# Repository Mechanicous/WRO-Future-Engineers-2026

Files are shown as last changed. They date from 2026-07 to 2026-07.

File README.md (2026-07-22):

<div align="center">

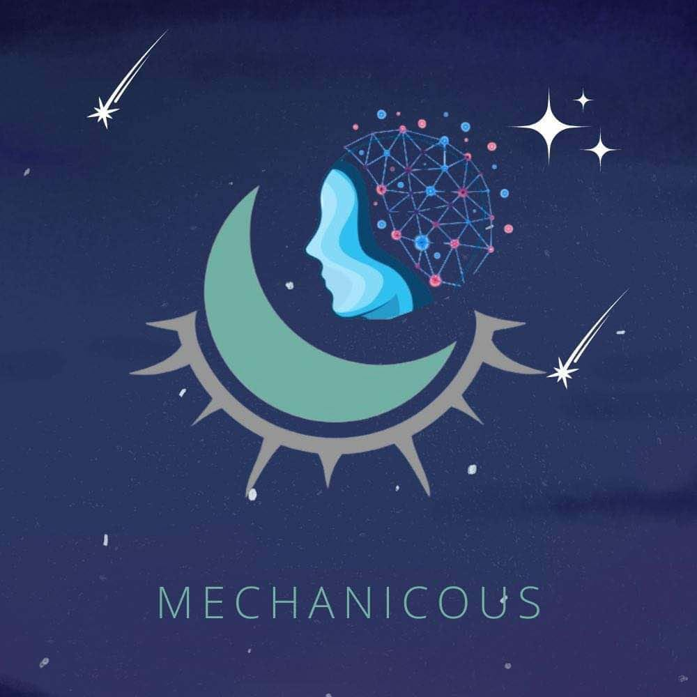
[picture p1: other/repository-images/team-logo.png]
Mechanicous team logo


# Mechanicous - MadBoy

**WRO Future Engineers 2026 engineering documentation**






[Demo Video](#demo-video) | [Rubric Map](#wro-2026-rubric-map) | [Build Guide](#robot-construction-guide) | [Source Code](./src/)

</div>

---

## Table Of Contents

- [Team](#team)
- [Challenge](#challenge)
- [Robot Overview](#robot-overview)
- [WRO 2026 Rubric Map](#wro-2026-rubric-map)
- [Mobility And Mechanical Design](#mobility-and-mechanical-design)
- [Power And Sensor Architecture](#power-and-sensor-architecture)
- [Software Architecture And Obstacle Strategy](#software-architecture-and-obstacle-strategy)
- [Systems Thinking And Engineering Decisions](#systems-thinking-and-engineering-decisions)
- [Robot Construction Guide](#robot-construction-guide)
- [Testing Workflow](#testing-workflow)
- [Demo Video](#demo-video)
- [Cost Report](#cost-report)
- [Repository Structure](#repository-structure)
- [Submission Checklist](#submission-checklist)

---

## Team

<table>
  <tr>
    <td align="center" width="33%">
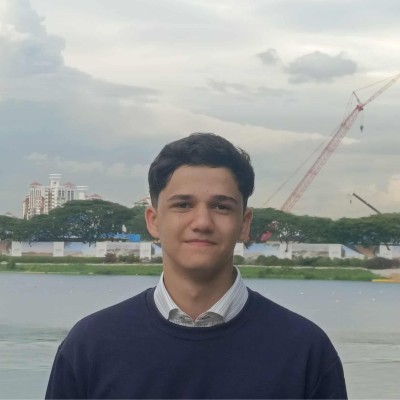
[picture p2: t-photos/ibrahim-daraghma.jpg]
Ibrahim Daraghma team member photo
      <br>
      <strong>Ibrahim Daraghma</strong><br>
      Role: Member<br>
      Focus: Designing And Coding
    </td>
    <td align="center" width="33%">
      Team member photo placeholder<br>
      <strong>Ali Foqha</strong><br>
      Role: Member<br>
      Focus: Coding And Thinking
    </td>
    <td align="center" width="33%">
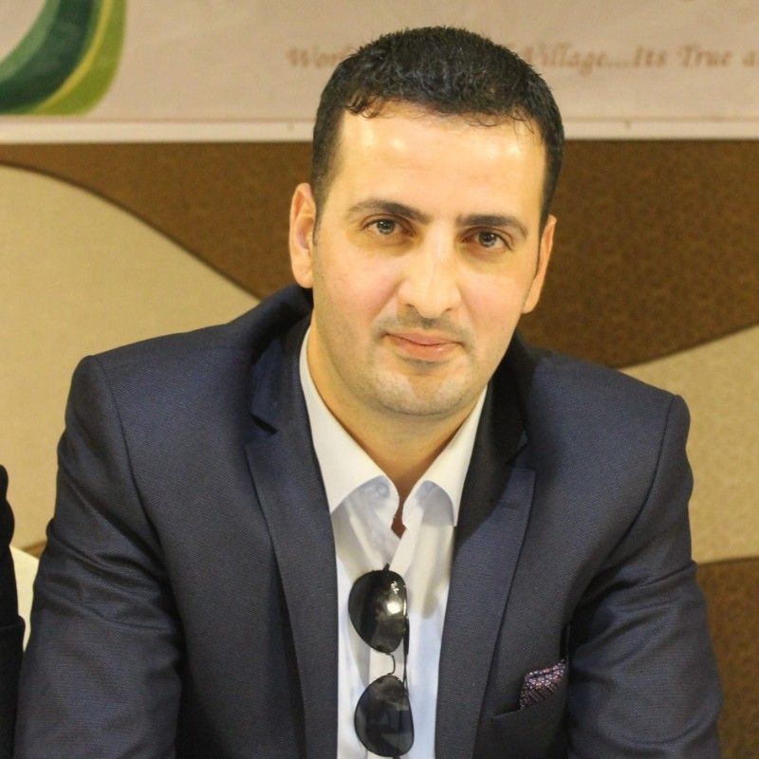
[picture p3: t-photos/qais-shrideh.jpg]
Qais Shrideh coach photo
      <br>
      <strong>Qais Shrideh</strong><br>
      Role: Coach<br>
      Focus: Team guidance
    </td>
  </tr>
</table>

Photos can be found in [`t-photos/`](./t-photos/).

---

## Challenge

WRO Future Engineers 2026 is a self-driving car challenge. The robot must drive autonomously on a field, handle randomized round conditions, complete Open Challenge and Obstacle Challenge runs, and document the full engineering process clearly enough for judges and other teams to understand the design.

The official 2026 documentation rubric is organized around five engineering areas:

- Mobility and mechanical design.
- Power and sensor architecture.
- Software architecture and obstacle strategy.
- Systems thinking and engineering decisions.
- Reproducibility and GitHub quality.

Official rules: [WRO 2026 Future Engineers General Rules](https://wro-association.org/wp-content/uploads/WRO-2026-Future-Engineers-Self-Driving-Cars-General-Rules.pdf)  
Official rubric: [WRO 2026 Future Engineers Documentation Rubric](https://wro-association.org/wp-content/uploads/WRO-2026-Future-Engineers-Documentation-Rubric.pdf)

---

## Robot Overview

<div align="center">

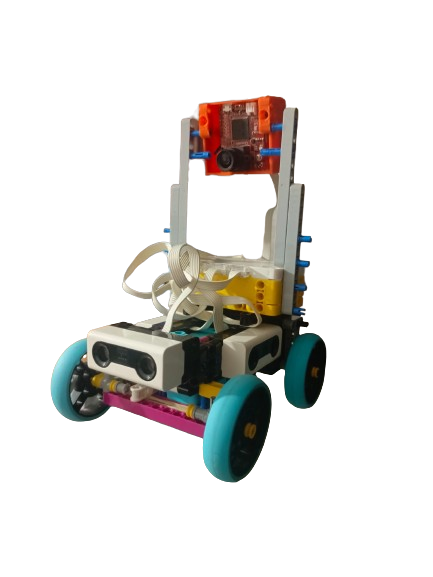
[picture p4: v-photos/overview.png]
MadBoy robot overview photo


</div>

| Item | Current Plan / Evidence |
| --- | --- |
| Robot name | MadBoy |
| Main controller | LEGO SPIKE Prime Hub |
| Programming platform | Pybricks MicroPython |
| Drive system | Rear-wheel drive using a SPIKE Large Angular Motor and rear differential gear system |
| Steering system | Front steering using a SPIKE Medium Angular Motor |
| Sensors | 3x LEGO ultrasonic sensors, SPIKE Prime integrated gyro/IMU, OpenMV H7 camera |
| Stage source code | Open Round: [`src/pybricks/open_round.py`](./src/pybricks/open_round.py); Obstacle Course: [`src/pybricks/obstacle_course.py`](./src/pybricks/obstacle_course.py) |
| Current behavior | Completes 3 laps in the Open Challenge round; Obstacle Challenge detection and strategy are working |
| Next behavior to implement | Improve consistency, tune steering center/wall centering, and add more test evidence |

### Vehicle Photos

Vehicle photos can be found in [`v-photos/`](./v-photos/).

<table>
  <tr>
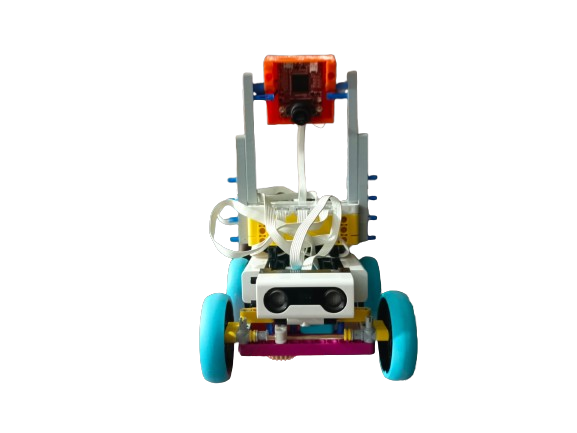
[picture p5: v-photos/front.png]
Front vehicle photo
    <td align="center"><br><strong>Front</strong></td>
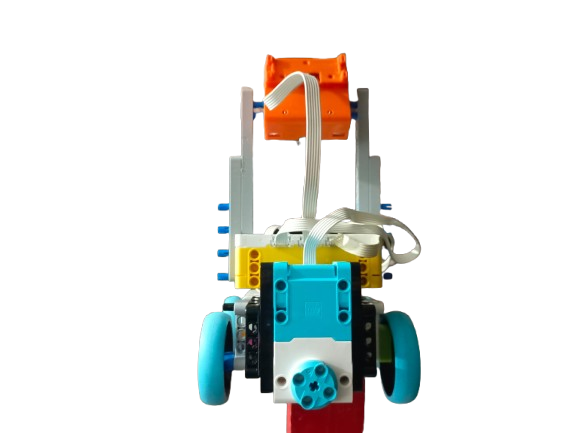
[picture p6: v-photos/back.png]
Back vehicle photo
    <td align="center"><br><strong>Back</strong></td>
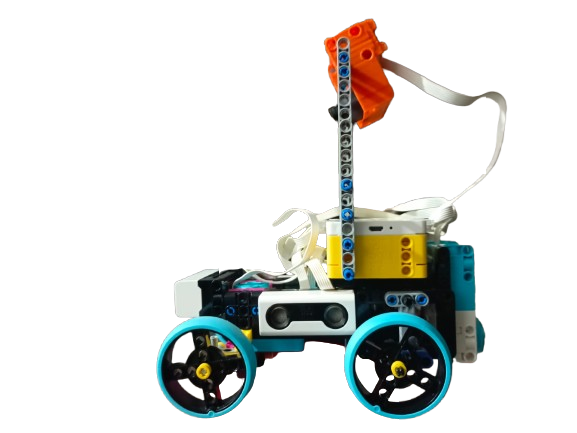
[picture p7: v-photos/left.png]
Left vehicle photo
    <td align="center"><br><strong>Left</strong></td>
  </tr>
  <tr>
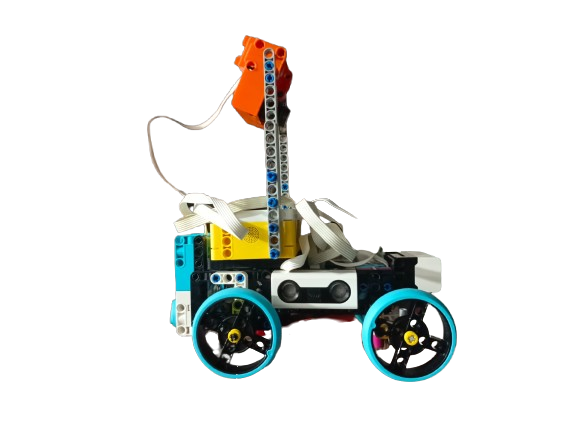
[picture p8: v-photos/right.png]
Right vehicle photo
    <td align="center"><br><strong>Right</strong></td>
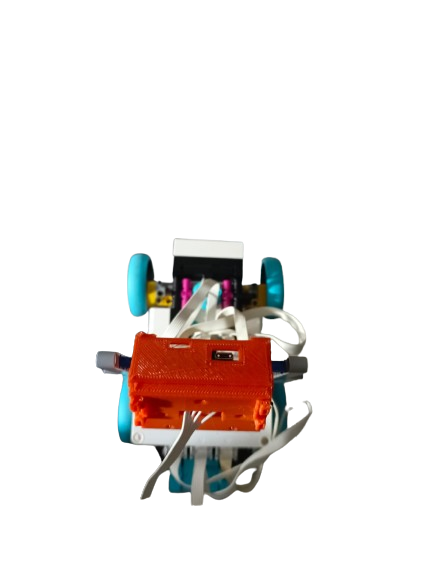
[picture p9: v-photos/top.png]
Top vehicle photo
    <td align="center"><br><strong>Top</strong></td>
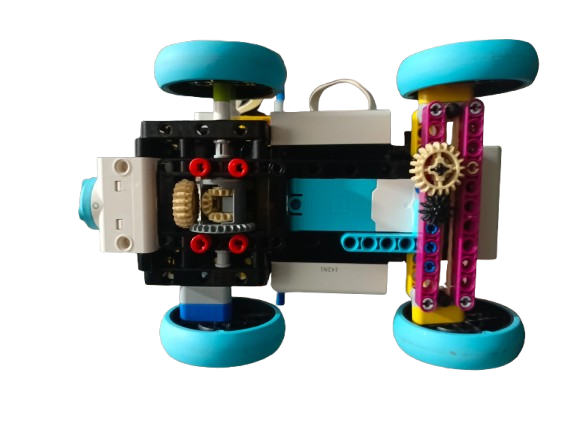
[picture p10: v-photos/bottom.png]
Bottom vehicle photo
    <td align="center"><br><strong>Bottom</strong></td>
  </tr>
</table>

---

## WRO 2026 Rubric Map

Use this table as the judge-facing index for the 2026 documentation rubric.

| 2026 Criterion | What Judges Need To See | Evidence Location | Status |
| --- | --- | --- | --- |
| Mobility and mechanical design | LEGO chassis, steering/drive mechanism, gear reasoning, dimensions, stability, iterations | [`models/Robot_Design.io`](./models/Robot_Design.io), [`v-photos/`](./v-photos/), [Mobility section](#mobility-and-mechanical-design) | Ready for presentation |
| Power and sensor architecture | SPIKE Prime hub, port map, battery/power notes, ultrasonic placement, integrated gyro use, OpenMV H7 UART communication using PUPRemote/LPF2 libraries, calibration, failure handling | [`schemes/`](./schemes/), [`schemes/port-map.md`](./schemes/port-map.md), [`other/calibration.md`](./other/calibration.md), [Power section](#power-and-sensor-architecture) | Ready for presentation |
| Software architecture and obstacle strategy | Pybricks code, gyro heading telemetry, flowchart/state machine, wall-following, OpenMV obstacle strategy, edge cases, tests | [`src/`](./src/), [`docs/software-architecture.md`](./docs/software-architecture.md), [Software section](#software-architecture-and-obstacle-strategy) | Documented; final code upload pending |
| Systems thinking and engineering decisions | Why LEGO SPIKE Prime was chosen, tradeoffs, risks, version history, testing response | [`docs/decisions.md`](./docs/decisions.md), [Decisions section](#systems-thinking-and-engineering-decisions) | Ready for presentation |
| Reproducibility and GitHub quality | README, source code, build steps, photos, diagrams, tests, meaningful commits | [`docs/build-instructions.md`](./docs/build-instructions.md), [`docs/tests.md`](./docs/tests.md), [Repository structure](#repository-structure) | Ready; final code upload pending |

---

## Mobility And Mechanical Design

### Mechanical Summary

| Subsystem | Design | Reasoning | Evidence |
| --- | --- | --- | --- |
| Chassis | LEGO SPIKE Prime / Technic construction, about 20 cm long x 13.5 cm wide x 22 cm high | Fast rebuilds, repeatable geometry, simpler maintenance, and within the WRO FE 30 cm x 20 cm x 30 cm size limit | [`v-photos/`](./v-photos/), [`models/Robot_Design.io`](./models/Robot_Design.io) |
| Drive motor | SPIKE Large Angular Motor driving a 20-tooth double bevel gear into a 28-tooth differential gear | Rear-wheel traction with smoother turning between left/right rear wheels | Approx. 20:28 reduction, wheel diameter about 5.5 cm; add speed tests |
| Steering | SPIKE Medium Angular Motor drives a 12-tooth gear into a 20-tooth gear, moving an arm linkage that steers the front wheels | Dedicated steering actuator keeps drive and steering control separate; 12:20 reduction improves steering torque | Steering range is about 45 degrees left and 45 degrees right |
| Sensors | Left/middle/right ultrasonic sensors, integrated gyro, OpenMV H7 | Distance, heading feedback, and vision/color detection | Sensor and camera heights documented below |
| Mounting | LEGO beams, frames, and pins | Easy iteration and legal reproducibility | Add build photos/model files |

### Powertrain

The robot uses rear-wheel drive. A SPIKE Large Angular Motor drives a beige 20-tooth double bevel gear, which drives the 28-tooth gear on the LEGO differential. This creates an approximate 20:28 reduction, so the differential turns about 0.71 times for each motor gear rotation while increasing torque by about 1.4x before friction losses. The differential contains three 12-tooth bevel gears so the left and right rear wheels can rotate at different speeds while turning.

### Dimensions

| Measurement | Approximate Value | Notes |
| --- | ---: | --- |
| Length | 20 cm | Within WRO FE 30 cm maximum length |
| Width | 13.5 cm | Within WRO FE 20 cm maximum width |
| Height | 22 cm | Within WRO FE 30 cm maximum height |
| Wheelbase | 10.3 cm | Front axle center to rear axle center |
| Front track width | 11.2 cm | Left front wheel center to right front wheel center |
| Rear track width | 11.2 cm | About the same as front track width |
| Wheel diameter | 5.5 cm | LEGO wheel/tire diameter |

Current size check: MadBoy fits inside the WRO Future Engineers 2026 maximum robot size of 30 cm length x 20 cm width x 30 cm height.

| Test | Result | What Changed |
| --- | --- | --- |
| Straight-line run | Completes 3 Open Challenge laps | Current drivetrain retained |
| Corner entry | Handles Open Challenge corners during completed 3-lap runs | Keep tuning for consistency |
| Three-minute endurance | Battery shows no noticeable slowdown during current runs | Exact runtime not measured |

### Steering

The robot uses a SPIKE Medium Angular Motor for steering. The motor drives a 12-tooth gear, which drives a 20-tooth gear connected to an arm linkage. Moving this arm moves the steering system and turns the front wheels. The maximum steering range is about 45 degrees left and 45 degrees right, which matches the `STEERING_LEFT_LIMIT_DEG = -45` and `STEERING_RIGHT_LIMIT_DEG = 45` limits in [`src/pybricks/open_round.py`](./src/pybricks/open_round.py).

### Chassis

The robot design is available as a Studio 2.0 file at [`models/Robot_Design.io`](./models/Robot_Design.io). It includes the step-by-step building instructions for MadBoy.

Use the model and build photos in [`models/`](./models/) to explain:

- Why the LEGO frame shape was chosen.
- How the hub, motors, and ultrasonic sensors are mounted.
- How weight is distributed.
- What changed between versions.

---

## Power And Sensor Architecture

### SPIKE Prime Port Map

Keep the active port map in [`schemes/port-map.md`](./schemes/port-map.md).

| Device | Current Port | Purpose | Notes |
| --- | --- | --- | --- |
| Drive motor | A | SPIKE Large Angular Motor for rear-wheel drive | Confirmed |
| Steering motor | E | SPIKE Medium Angular Motor for front steering | Confirmed |
| Left ultrasonic sensor | B | Measure left wall distance | Confirmed |
| Middle/front ultrasonic sensor | D | Measure front path and obstacle distance | Confirmed |
| Right ultrasonic sensor | F | Measure right wall distance | Confirmed |
| Integrated gyro/IMU | SPIKE Prime Hub | Heading and turn feedback | Built into hub |
| OpenMV H7 camera | C | Vision and obstacle color detection | Confirmed UART protocol; PUPRemote/LPF2 libraries used in code |

### Power Distribution

The LEGO SPIKE Prime rechargeable battery powers the hub and connected Powered Up motors/sensors through the hub ports. Before each run, the team charges the hub battery to full, checks that every cable is connected, confirms that the LEGO structure is steady and sturdy, and verifies that all motors, sensors, and camera parts are in place.

Current battery evidence is qualitative: the SPIKE Prime Hub battery lasts a long time during team testing, and no noticeable slowdown has been reported during current Open Challenge runs. Exact runtime has not been tracked yet.

| Connection | Details |
| --- | --- |
| Power source | SPIKE Prime rechargeable battery inside the hub |
| Motor/sensor power | Hub ports power the two motors and three ultrasonic sensors |
| OpenMV link | UART on SPIKE Prime port C, with PUPRemote/LPF2 Python libraries packaging messages |
| Pre-run check | Full battery, firm cables, sturdy LEGO frame, all sensors/motors/camera in place |

### Sensor Placement

| Sensor | Position | Purpose | Calibration |
| --- | --- | --- | --- |
| Left ultrasonic | Left side, about 5 cm from the floor, facing outward to the left | Wall distance and lane centering | Test readings at known distances |
| Middle/front ultrasonic | Middle/front, about 6 cm from the floor, facing forward | Front safety stop and obstacle approach distance | Test close-range stop threshold |
| Right ultrasonic | Right side, about 5 cm from the floor, facing outward to the right | Wall distance and lane centering | Test readings at known distances |
| Integrated gyro/IMU | Inside SPIKE Prime Hub, hub lying flat with USB port facing left | Heading tracking and turn feedback | Reset heading at start line and test drift |
| OpenMV H7 camera | Lens about 17.5 cm from the floor, tilted about 5 degrees | Red/green obstacle detection and vision strategy | Calibrate thresholds after mounting |

The OpenMV H7 communicates with the SPIKE Prime Hub on port C using the UART communication protocol. The code uses the PUPRemote/LPF2 Python libraries to package and exchange the data.

### Failure Handling

| Failure Mode | Detection | Response |
| --- | --- | --- |
| Front sensor reports too close | Front distance below threshold | Stop drive motor |
| Front sensor unavailable | Reading rejected by software | Stop until reading returns |
| Left/right sensor noisy or out of range | Clamp steering correction | Keep steering limited |
| Gyro heading drift | Heading check becomes inaccurate | Reset at start and record drift tests |
| OpenMV unavailable or uncalibrated | Vision-based obstacle classification is unavailable | Fall back to safe behavior until integration is tested |
| Low hub battery | Battery not fully charged before a run | Charge the SPIKE Prime Hub battery to full before testing or official runs |

---

## Software Architecture And Obstacle Strategy

### Stage Code

The robot software is organized by stage:

- [`src/pybricks/open_round.py`](./src/pybricks/open_round.py) is used for the Open Challenge / Open Round stage.
- [`src/pybricks/obstacle_course.py`](./src/pybricks/obstacle_course.py) is reserved for the Obstacle Challenge stage and currently contains `#soon` until the team publishes that code.

The Open Round program currently:

- Runs on a LEGO SPIKE Prime Hub using Pybricks MicroPython.
- Reads three ultrasonic sensors: left, middle/front, and right.
- Resets and reads the SPIKE Prime integrated gyro heading.
- Uses the middle/front ultrasonic sensor as a safety stop.
- Completes 3 laps in the Open Challenge round.
- Uses left/right distance difference for wall-balancing steering.
- Uses `src/openmv/` for OpenMV H7 vision code and UART communication notes.
- Keeps all port assignments and control constants near the top of the file for easy tuning.

### Current Flow

```mermaid
flowchart TD
    A["Power on SPIKE Prime"] --> B["Initialize hub, motors, ultrasonic sensors, and gyro"]
    B --> C["Wait for center button"]
    C --> D["Center steering and reset gyro heading"]
    D --> E["Read distances and heading"]
    E --> F{"Front distance safe?"}
    F -- "No" --> G["Stop drive motor"]
    F -- "Yes" --> H["Compare left and right distances"]
    H --> I["Calculate steering correction"]
    I --> J["Drive forward"]
    G --> E
    J --> E
```

### Final State Machine Template

| State | Purpose | Entry Condition | Exit Condition | Notes |
| --- | --- | --- | --- | --- |
| Init | Verify ports, sensors, motors, and battery | Program start | Hardware ready | Implemented in starter code |
| WaitForStart | Keep robot still before official run | Hub center button or start condition | Start pressed | Implemented in starter code |
| OpenChallengeDrive | Complete 3 laps without colored obstacles | Open Challenge run starts | 3 laps complete or timeout | Working |
| WallCentering | Maintain position using side ultrasonic sensors | Driving straight/curving | Corner or obstacle detected | Starter code exists |
| ObstacleDetect | Detect obstacle approach with front sensor and OpenMV H7 vision | Obstacle Challenge | Obstacle classified | Working |
| AvoidRed | Pass red obstacle according to WRO rules | Red obstacle detected | Safe path restored | Working |
| AvoidGreen | Pass green obstacle according to WRO rules | Green obstacle detected | Safe path restored | Working |
| Parking | Not used by team strategy | Parking/start-from-parking not selected | N/A | Not planned |
| FailSafeStop | Stop safely | Unsafe or invalid readings | Manual reset or safe reading | Starter code exists |

### Algorithms To Explain

- Wall centering from left/right ultrasonic sensors.
- Heading feedback from the SPIKE Prime integrated gyro.
- Front obstacle distance threshold.
- Corner detection.
- Lap counting.
- Obstacle color detection strategy using OpenMV H7.
- Recovery from bad ultrasonic readings.
- Steering calibration and sign testing.

---

## Systems Thinking And Engineering Decisions

Judges look for the reasoning behind the design, not only the final robot.

| Decision | Options Compared | Chosen Option | Why | Test Evidence |
| --- | --- | --- | --- | --- |
| Controller platform | Arduino custom electronics vs LEGO SPIKE Prime | LEGO SPIKE Prime | Faster iteration, integrated battery, robust ports, Pybricks support | Current robot completes 3 Open Challenge laps |
| Programming language | Arduino C++ vs Pybricks MicroPython | Pybricks MicroPython | Cleaner high-level motor/sensor APIs and easier tuning | Stage code in `src/pybricks/open_round.py` and `src/pybricks/obstacle_course.py` |
| Distance sensing | VL53L1X ToF vs LEGO ultrasonic | Three LEGO ultrasonic sensors | Matches new LEGO build and simple wall-distance measurements | 20 cm calibration recorded |
| Heading feedback | External IMU vs SPIKE Prime integrated gyro | SPIKE Prime integrated gyro | Built into the hub and available through Pybricks | Orientation documented; MadBoy drift measurement still needed |
| Vision sensor | No camera vs OpenMV H7 | OpenMV H7 | Supports red/green obstacle detection with onboard vision processing and UART communication to the SPIKE Hub using PUPRemote/LPF2 libraries | Obstacle detection and strategy working |
| Navigation strategy | Gyro heading hold vs ultrasonic wall centering vs fused approach | Ultrasonic wall centering plus integrated gyro feedback | Uses current sensors while keeping heading data available | Current wall-centering behavior documented |

### Iteration Log

| Version | Change | Problem Solved | Evidence |
| --- | --- | --- | --- |
| v0.1 | Arduino prototype with BMI160 and VL53L1X sensors | First heading-hold experiment | Git history |
| v0.2 | Switched to LEGO SPIKE Prime, Pybricks, and 3 ultrasonic sensors | Simpler integrated robot platform | Current README and source |
| v0.3 | Added integrated gyro, OpenMV H7, confirmed ports, dimensions, tests, and BOM | Prepared repository for presentation | Current README, docs, photos, and test logs |

### Risks

| Risk | Impact | Mitigation | Test |
| --- | --- | --- | --- |
| Ultrasonic reflections | Wrong distance near angled walls or obstacles | Use repeated tests, clamp steering, tune thresholds | 20 cm calibration recorded; more distances recommended |
| Gyro heading drift | Turns or lap logic may become inaccurate | Reset at start and test drift over time | Internet reference documented; MadBoy measurement still needed |
| OpenMV lighting sensitivity | Red/green detection may fail under different lighting | Calibrate thresholds on the real field | Detection/strategy working; formal accuracy count still needed |
| Steering sign reversed | Robot steers into wall | Test at low speed and flip `STEERING_SIGN` if needed | Current sign passes: closer to left wall steers right/away |
| LEGO structure flex | Sensor angle or steering changes during run | Reinforce mounts and inspect after runs | Pre-run structure check documented |
| Hub battery low | Motor speed changes during run | Charge to full before each run and check cable/structure stability | No noticeable slowdown reported; exact runtime not tracked |

Detailed decision records belong in [`docs/decisions.md`](./docs/decisions.md).

---

## Robot Construction Guide

The complete mechanical construction guide is stored in [`models/Robot_Design.io`](./models/Robot_Design.io). Open it with Studio 2.0 to view the full MadBoy model and follow the included step-by-step building instructions. No separate written LEGO assembly guide is needed because the Studio file is the official build reference.

Additional setup notes are in [`docs/build-instructions.md`](./docs/build-instructions.md), including dimensions, port wiring, sensor placement, software upload, and the pre-run checklist.

### Upload Pybricks Code

1. Install Pybricks firmware on the SPIKE Prime Hub if it is not already installed.
2. Open [Pybricks Code](https://code.pybricks.com/) in a browser.
3. Connect the SPIKE Prime Hub.
4. Open the program for the current stage: [`src/pybricks/open_round.py`](./src/pybricks/open_round.py) for Open Round, or [`src/pybricks/obstacle_course.py`](./src/pybricks/obstacle_course.py) when the Obstacle Course code is published.
5. Confirm the port constants match the real robot.
6. Upload/run the program.
7. Start at low speed and verify steering direction before full-speed tests.

---

## Testing Workflow

Testing evidence belongs in [`docs/tests.md`](./docs/tests.md).

| Test | Metric | Target | Current Result |
| --- | --- | --- | --- |
| Ultrasonic accuracy | Error at known distances | +/- 1 cm reference target | 20 cm test: left +0.5 cm, front +1.2 cm, right +0.1 cm |
| Gyro heading drift | Degrees drift over time | Measure MadBoy; internet bad-case reference up to about 1 deg/s | Not measured yet on MadBoy |
| Front safety stop | Stop distance from obstacle | Object at 10 cm | Robot stopped at about 10 cm, +/- 1 cm |
| Steering center | Straight run drift | Straight run after centering | Drifts left or right depending on the last steering adjustment |
| Steering sign | Correct response to left/right offset | Closer to left wall should steer right/away | Passes with `STEERING_SIGN = 1` |
| Wall centering | Average side-distance error | Stay between walls during Open Challenge | Sometimes centered; sometimes closer to one wall, so side gain and steering center need tuning |
| Rear differential smoothness | Binding, clicking, or slipping | Smooth rear-wheel drive | Drives smoothly with LEGO gears; no binding/slipping observed |
| Open Challenge | Laps and time | 3 laps | Working: completes 3 laps |
| OpenMV color detection | Red/green classification accuracy | Working obstacle detection | Detection working; add formal accuracy test later |
| Obstacle Challenge | Obstacle handling and score | Working detection and strategy | Strategy ready and working |
| Parking | Final position and alignment | Not used | Team will not park or start from parking area |

---

## Demo Video

Add public video links in [`video/video.md`](./video/video.md).

| Video | Link | Robot Version | Date |
| --- | --- | --- | --- |
| Open Challenge run | [YouTube](https://youtu.be/ipjWBAg2dVM) | MadBoy | July 21, 2026 |
| Obstacle Challenge run | Not published yet | MadBoy | Evidence pending |

---

## Cost Report

Maintain the full bill of materials in [`other/bill-of-materials.md`](./other/bill-of-materials.md). The current robot used parts that were already available to the team, so the actual team spending for the listed robot electronics is 0 USD. The replacement-cost estimate below is for another team buying the main electronics separately.

| Category | Estimated Cost | Notes |
| --- | ---: | --- |
| Actual team spending | 0 USD | Parts were already available |
| Main electronics replacement estimate | about 669 USD | Hub, Large Angular Motor, Medium Angular Motor, three ultrasonic sensors, OpenMV H7 |
| LEGO structural parts | Variable / already available | Beams, frames, wheels, gears, differential |
| Power | Included / already available | SPIKE Prime rechargeable battery and charger/cable |
| Total replacement estimate | about 669 USD plus variable LEGO structure cost | See detailed BOM |

---

## Repository Structure

| Folder | Purpose |
| --- | --- |
| [`src/`](./src/) | Pybricks MicroPython robot code and OpenMV H7 vision notes |
| [`schemes/`](./schemes/) | SPIKE Prime port map, gyro/camera notes, sensor placement, and power/connection diagrams |
| [`models/`](./models/) | Studio 2.0 LEGO model, build instructions, build photos, and reproducible assembly notes |
| [`v-photos/`](./v-photos/) | Vehicle photos from all required angles |
| [`t-photos/`](./t-photos/) | Team photos |
| [`video/`](./video/) | Demo video links |
| [`docs/`](./docs/) | Engineering journal, build guide, tests, decisions |
| [`other/`](./other/) | BOM, calibration notes, datasets, hardware specs, supporting assets |

Sensor reference values from LEGO and Pybricks are summarized in [`docs/sensor-reference.md`](./docs/sensor-reference.md).

---

## Submission Checklist

- [ ] Team details and team photos are complete. Missing Ali Foqha photo.
- [x] Vehicle photos show front, back, left, right, top, bottom, wiring/ports, and sensors.
- [x] README explains the LEGO SPIKE Prime robot clearly and links to all evidence.
- [ ] Engineering journal tells the design story and includes reasoning. Needs more dated narrative entries from the team.
- [x] Mechanical design includes LEGO model/build files, photos, and dimensions.
- [x] SPIKE Prime port map and sensor placement measurements are included.
- [x] Ultrasonic sensor calibration is documented.
- [ ] Integrated gyro heading reset/drift tests are documented with MadBoy measurements.
- [x] OpenMV H7 mounting, calibration plan, and communication method are documented.
- [x] Software architecture includes flowchart/state machine and obstacle strategy.
- [x] Tests include results, metrics, and changes made after testing.
- [x] Decisions include alternatives, tradeoffs, and risks.
- [x] Build instructions let another team reproduce the robot.
- [ ] Demo video links are public. Open Challenge video is public; Obstacle Challenge video is still pending.
- [x] Git history has meaningful commits.

---

## License

This project is released under the [MIT License](./LICENSE).

Third-party PUPRemote/LPF2 communication libraries are listed in
[`THIRD_PARTY_NOTICES.md`](./THIRD_PARTY_NOTICES.md).

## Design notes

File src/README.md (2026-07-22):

# Source Code

This folder contains the stage-specific robot software.

## Stage Programs

- `pybricks/open_round.py` is used for the Open Challenge / Open Round stage.
- `pybricks/obstacle_course.py` is reserved for the Obstacle Challenge stage and will be filled when the team is ready to publish that code.

The project now uses:

- LEGO SPIKE Prime Hub.
- Pybricks MicroPython.
- LEGO SPIKE Prime integrated gyro/IMU for heading feedback.
- Three LEGO ultrasonic sensors:
  - Left.
  - Middle/front.
  - Right.
- OpenMV H7 camera module for vision/color detection.

The old Arduino/BMI160/VL53L1X prototype is no longer active. It remains available in Git history for reference, but the repository documentation now follows the LEGO SPIKE Prime design.

## Current Behavior

- Initializes the SPIKE Prime Hub, rear-drive Large Angular Motor, steering Medium Angular Motor, and three ultrasonic sensors.
- Resets and reports the SPIKE Prime integrated gyro heading.
- Waits for the hub center button before driving.
- Stops when the middle/front ultrasonic sensor reports an unsafe distance.
- Completes 3 laps in the Open Challenge round.
- Uses left/right ultrasonic distance difference for wall-centering steering.
- Prints simple telemetry for tuning.

## Files

| File | Purpose |
| --- | --- |
| `pybricks/open_round.py` | Open Challenge / Open Round program using gyro heading and ultrasonic distance correction |
| `pybricks/obstacle_course.py` | Obstacle Challenge program location; currently reserved until the team publishes this stage code |
| `pybricks/README.md` | Pybricks setup, port constants, and tuning notes |
| `lib/pybricks/pupremote_hub.py` | Hub-side PUPRemote library for reading OpenMV data |
| `lib/openmv/lpf2.py` | OpenMV-side LPF2 communication library |
| `lib/openmv/pupremote.py` | OpenMV-side PUPRemote library |
| `lib/README.md` | Third-party library upload notes and license notice |
| `openmv/README.md` | OpenMV H7 vision module notes |
| `openmv/main.py` | OpenMV H7 camera code draft; publish after team review/testing |

## Presentation Status

- Motor and sensor ports are confirmed in `../schemes/port-map.md`.
- Steering sign and front safety stop are tested; steering center and wall-centering consistency remain tuning targets.
- Integrated gyro heading reset is documented; MadBoy-specific drift measurement remains a future calibration task.
- OpenMV H7 communicates with the SPIKE Prime Hub through UART on port C, using PUPRemote/LPF2 Python libraries in code.
- Open Challenge 3-lap behavior and Obstacle Challenge working status are documented in `../docs/tests.md`.

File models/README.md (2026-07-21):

# Models

Add mechanical design files and reproducible build materials for the LEGO SPIKE Prime robot.

Useful formats:

- LEGO Studio `.io` files.
- Step-by-step build photos.
- Dimension drawings for wheelbase, track width, and sensor placement.
- Custom part CAD only if non-LEGO parts are used.

## Current Model

- `Robot_Design.io` - LEGO Studio 2.0 model for MadBoy. This file includes the step-by-step building instructions for the robot.
- `openmv-camera-case.stl` - 3D printable case for the OpenMV camera.

Open `Robot_Design.io` with Studio 2.0 to inspect the LEGO design and follow the assembly steps.

## External Model Sources

- `openmv-camera-case.stl` comes from the Instructables project [Backpack #1: OpenMV Camera](https://www.instructables.com/Backpack-1-OpenMV-Camera/). Keep this source link with the file for attribution and traceability.

## Presentation Notes

- Keep `Robot_Design.io` updated when the physical robot changes.
- Steering linkage: SPIKE Medium Angular Motor drives a 12-tooth gear into a 20-tooth gear, moving an arm linkage with about 45 degrees left/right steering range.
- Rear differential gear layout: SPIKE Large Angular Motor drives a 20-tooth double bevel gear into a 28-tooth LEGO differential gear; the differential contains three 12-tooth bevel gears.
- Ultrasonic sensor mount heights and facing directions are documented in `../schemes/port-map.md`.
- SPIKE Prime Hub orientation is documented for integrated gyro heading.
- OpenMV H7 camera mount height and tilt are documented; field of view remains a later calibration measurement.
- Current approximate dimensions: length 20 cm, width 13.5 cm, height 22 cm, wheelbase 10.3 cm, front/rear track width 11.2 cm, wheel diameter 5.5 cm.
- Wheel, axle, and gearing details are summarized in the README and build instructions.
- Include enough detail that another team could rebuild the robot.

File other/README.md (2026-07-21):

# Other Materials

Use this folder for supporting files that help another team reproduce or understand the robot.

Suggested files:

- `bill-of-materials.md`
- `calibration.md`
- `repository-images/` for README graphics and team assets
- hardware datasheets
- datasets or sample sensor logs
- setup notes for cameras, boards, or computers
- communication protocol notes

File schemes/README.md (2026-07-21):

# Schemes

Add diagrams that show how the LEGO SPIKE Prime robot is connected and how the sensors are placed.

Recommended files:

- `port-map.md` for the active SPIKE Prime port assignments.
- `port-map.png` or `port-map.pdf` for a visual hub connection diagram.
- `sensor-placement.png` or `sensor-placement.pdf` for left, middle/front, and right ultrasonic sensor placement.
- `gyro-and-camera-placement.png` or `gyro-and-camera-placement.pdf` for SPIKE Prime Hub orientation and OpenMV H7 mounting.
- `power-notes.md` if you want to document SPIKE Prime battery behavior and charging procedure.

The 2026 documentation rubric expects power/sensor architecture, sensor placement, calibration, and enough detail for another team to reproduce the robot.

## Presentation Status

- Every SPIKE Prime port is confirmed in `port-map.md`.
- Sensor placement is documented with distances, heights, and facing directions.
- SPIKE Prime Hub orientation is documented for integrated gyro heading.
- Documented OpenMV H7 camera position and UART communication through SPIKE Prime port C using PUPRemote/LPF2 Python libraries. Add field of view after calibration.
- Documented pre-run power routine: charge the SPIKE Prime Hub battery to full, check all cables, verify the structure is steady and sturdy, and confirm all parts are in place.

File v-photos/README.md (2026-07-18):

# Vehicle Photos

Add photos of the vehicle from every important angle.

Recommended set:

- Front
- Back
- Left side
- Right side
- Top
- Bottom
- Wiring close-up
- Sensor placement close-up

Use clear lighting and avoid heavy editing so judges can inspect the real robot.

Current photos:

- `back.png` - rear view of MadBoy.
- `bottom.png` - underside view of MadBoy.
- `front.png` - front view of MadBoy.
- `left.png` - left side view of MadBoy.
- `overview.png` - angled overview photo of MadBoy.
- `right.png` - right side view of MadBoy.
- `top.png` - top view of MadBoy.

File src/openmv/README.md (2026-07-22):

# OpenMV H7 Vision Module

This folder is reserved for the OpenMV H7 camera program and integration notes.

## Role

The OpenMV H7 is used for:

- detecting red and green traffic signs/obstacles,
- sending obstacle classification to the SPIKE Prime Hub,
- supporting the Obstacle Challenge strategy.

## Integration Notes

- Communication protocol: UART.
- SPIKE Prime port: C.
- Code libraries: PUPRemote/LPF2 Python libraries package the messages in code.
- Camera mounting: lens about 17.5 cm from the floor, tilted about 5 degrees.
- Current status: obstacle detection and red/green strategy are working in team testing.

## Message Plan

The camera should send obstacle information such as:

- obstacle color,
- obstacle position in the camera frame,
- confidence or detected area,
- whether no valid obstacle is visible.

## Files

| File | Purpose |
| --- | --- |
| `main.py` | OpenMV camera program location; final team-tested code will be added when ready |
| `../lib/openmv/lpf2.py` | LPF2 communication layer used by the camera side |
| `../lib/openmv/pupremote.py` | PUPRemote sensor-side helper used by the camera side |

Copy both OpenMV library files to the OpenMV H7 together with `main.py` when the final camera program is ready.

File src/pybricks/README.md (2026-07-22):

# Pybricks Program

This folder contains one program file for each WRO Future Engineers stage.

## Hardware

- LEGO SPIKE Prime Hub.
- SPIKE Large Angular Motor for rear-wheel drive.
- SPIKE Medium Angular Motor for steering.
- SPIKE Prime integrated gyro/IMU for heading feedback.
- Three ultrasonic sensors:
  - left,
  - middle/front,
  - right.
- OpenMV H7 for vision/color detection.

The robot uses a rear differential gear system in the drivetrain. This is a mechanical differential, not differential steering.

## Port Map

| Device | Port |
| --- | --- |
| SPIKE Large Angular Motor, rear-wheel drive | A |
| Left ultrasonic sensor | B |
| OpenMV H7 via UART | C |
| Middle/front ultrasonic sensor | D |
| SPIKE Medium Angular Motor, steering | E |
| Right ultrasonic sensor | F |

The judge-facing port map is in `../../schemes/port-map.md`.

## First Run Checklist

1. Put the robot on blocks so the wheels can spin safely.
2. Run the program for the current stage.
3. Confirm all three ultrasonic readings are printed.
4. Confirm the heading value is printed and near 0 after the start button is pressed.
5. Check that the drive motor direction is correct.
6. Check that steering centers correctly.
7. If steering turns the wrong way, flip `STEERING_SIGN` in the stage program being tested.
8. Start with low `DRIVE_POWER` before track testing.

## Program Files

| File | Purpose |
| --- | --- |
| `open_round.py` | Open Challenge / Open Round program using gyro heading correction plus left/right/front ultrasonic distance correction |
| `obstacle_course.py` | Obstacle Challenge program location; currently marked `#soon` until the team publishes this stage code |
| `../lib/pybricks/pupremote_hub.py` | Hub-side PUPRemote library for receiving OpenMV H7 data on port C |

## OpenMV H7

OpenMV H7 communicates with the SPIKE Prime Hub through UART on port C. PUPRemote/LPF2 are Python libraries used by the code to package messages; they are not the communication protocol.

The hub-side library is stored at `../lib/pybricks/pupremote_hub.py`. Copy it to the SPIKE Prime Hub together with the final stage program that reads OpenMV data.

The final integrated reader/strategy code will be added after team testing is ready to publish.

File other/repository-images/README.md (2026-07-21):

# Repository Images

This folder contains README image assets.

Current assets:

- `team-logo.png` - Mechanicous team logo used in the README header.
- `placeholder-team.svg` - temporary placeholder used only for Ali Foqha until his real team photo is added.

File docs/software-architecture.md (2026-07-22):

# Software Architecture

This project now uses LEGO SPIKE Prime with Pybricks MicroPython.

## Stage Programs

Source files:

- `../src/pybricks/open_round.py` is used for the Open Challenge / Open Round stage.
- `../src/pybricks/obstacle_course.py` is reserved for the Obstacle Challenge stage and currently contains `#soon` until the team publishes that code.

Current control flow:

1. Initialize the SPIKE Prime Hub.
2. Initialize the SPIKE Large Angular Motor for rear-wheel drive, SPIKE Medium Angular Motor for steering, three ultrasonic sensors, and integrated hub gyro.
3. Wait for the hub center button.
4. Center the steering motor and reset the integrated gyro heading.
5. Read left, middle/front, and right ultrasonic distances and gyro heading.
6. Stop if the middle/front sensor reports an unsafe or invalid distance.
7. Compare left and right distances.
8. Convert side-distance error into a steering target.
9. Drive forward while repeating the loop.
10. Complete 3 laps in the Open Challenge round.

## Flowchart

```mermaid
flowchart TD
    A["Startup"] --> B["Initialize SPIKE Prime hub"]
    B --> C["Initialize motors, ultrasonic sensors, and gyro"]
    C --> D["Wait for center button"]
    D --> E["Center steering and reset gyro heading"]
    E --> F["Read distances and heading"]
    F --> G{"Front path safe?"}
    G -- "No" --> H["Stop drive motor"]
    G -- "Yes" --> I["Calculate side-distance steering"]
    I --> J["Drive forward"]
    H --> F
    J --> F
```

## Software Modules

| Area | Current Implementation | Next Work |
| --- | --- | --- |
| Hardware setup | Port constants and Pybricks device objects in `open_round.py` | Confirm Large Angular Motor and Medium Angular Motor ports |
| Distance reading | `read_distance()` validates ultrasonic readings | Add smoothing if needed |
| Heading reading | `hub.imu.reset_heading()` and `hub.imu.heading()` use the integrated gyro | Test drift and hub orientation |
| Front safety | Stop/resume thresholds with hysteresis | Tune thresholds on track |
| Wall centering | Left/right distance difference with gain | Current result is sometimes centered and sometimes closer to one wall; tune gain after improving steering center reset |
| Run control | Button start and 180-second timeout | Add official lap/end behavior |
| OpenMV vision | OpenMV H7 communicates over UART on SPIKE Prime port C; PUPRemote/LPF2 libraries package the data | Detection working; add formal accuracy evidence |
| Obstacle challenge | Detection and strategy are ready and working | Add score/run evidence |

## State Machine Plan

| State | Purpose | Entry Condition | Exit Condition | Status |
| --- | --- | --- | --- | --- |
| Init | Configure hub, motors, sensors, constants | Program starts | Devices ready | Starter code |
| WaitForStart | Hold robot until team starts run | Init complete | Center button pressed | Starter code |
| OpenDrive | Drive using ultrasonic wall centering | Start pressed | 3 laps complete, obstacle, or timeout | Working |
| CornerHandling | Turn through course corners | Corner detected | Straight section found | Working in Open Challenge runs; continue consistency tuning |
| ObstacleDetect | Detect red/green obstacle with OpenMV H7 | Obstacle Challenge enabled | Obstacle classified | Working |
| AvoidRed | Pass red obstacle correctly | Red obstacle detected | Safe path restored | Working |
| AvoidGreen | Pass green obstacle correctly | Green obstacle detected | Safe path restored | Working |
| Parking | Not used by team strategy | N/A | N/A | Not planned |
| FailSafeStop | Stop when readings are unsafe | Invalid/close front reading | Manual reset or safe reading | Starter code |

## Edge Cases To Document

- Ultrasonic reading is `None`, too close, or out of range.
- Left/right readings disagree strongly.
- Sensor sees an angled wall and reports a false long distance.
- Gyro heading drifts or is reset while robot is not aligned.
- OpenMV H7 loses red/green accuracy under different lighting.
- Steering sign is reversed.
- Robot starts too close to a wall or obstacle.
- Hub battery is low and motor speed changes.

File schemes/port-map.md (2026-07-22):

# LEGO SPIKE Prime Port Map

Keep this file synchronized with the stage programs in `../src/pybricks/`.

| Port | Device | Purpose | Status |
| --- | --- | --- | --- |
| A | SPIKE Large Angular Motor | Rear-wheel drive through differential gear system | Confirmed |
| B | Left ultrasonic sensor | Left wall distance | Confirmed |
| C | OpenMV H7 via UART | Red/green pillar vision data using PUPRemote/LPF2 libraries | Confirmed |
| D | Middle/front ultrasonic sensor | Front obstacle/path distance | Confirmed |
| E | SPIKE Medium Angular Motor | Front steering linkage | Confirmed |
| F | Right ultrasonic sensor | Right wall distance | Confirmed |
| Hub IMU | SPIKE Prime integrated gyro/IMU | Heading and turn feedback | Built in |

## Sensor Placement Notes

- Left ultrasonic height from floor: about 5 cm.
- Left ultrasonic angle relative to robot centerline: faces outward to the left.
- Middle/front ultrasonic height from floor: about 6 cm.
- Middle/front ultrasonic offset from robot centerline: centered at the front.
- Right ultrasonic height from floor: about 5 cm.
- Right ultrasonic angle relative to robot centerline: faces outward to the right.
- SPIKE Prime Hub orientation: hub is lying flat, with the USB port facing the robot's left side.
- OpenMV H7 camera lens height: about 17.5 cm from the floor.
- OpenMV H7 camera angle: tilted about 5 degrees.
- OpenMV H7 communication: UART protocol on SPIKE Prime port C; PUPRemote/LPF2 Python libraries are used by the OpenMV and Pybricks code.
- OpenMV H7 field of view: not measured yet; camera lens height, tilt, port, and UART communication method are documented.
- Port C cable path: routed from OpenMV H7 to the SPIKE Prime Hub port C.

## Diagram Notes

The repository currently documents the connection plan in tables and robot photos. A future visual diagram can show:

- Hub location.
- Cable routing.
- Motor ports.
- Rear differential gear system.
- Sensor ports.
- SPIKE Prime Hub orientation for gyro heading.
- OpenMV H7 mounting and communication path.
- Ultrasonic sensor field of view.

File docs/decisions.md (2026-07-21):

# Engineering Decisions

Use this file to show why the team chose each design, not only what the final design is.

## Decision Records

### Decision: Move From Arduino Prototype To LEGO SPIKE Prime

- Date: 2026-07-11
- Context: The team stopped using the Arduino, BMI160, VL53L1X sensors, servo, and custom wiring prototype.
- Options considered: Continue custom Arduino electronics, or rebuild on LEGO SPIKE Prime.
- Decision: Use LEGO SPIKE Prime with Pybricks MicroPython.
- Reasoning: SPIKE Prime gives an integrated hub, battery, ports, LEGO motor/sensor ecosystem, and faster mechanical iteration.
- Tradeoffs: Less direct low-level electronics control, ultrasonic readings may be less precise than ToF sensors, and the robot needs careful LEGO structural rigidity.
- Test evidence: Current LEGO SPIKE Prime robot completes 3 Open Challenge laps.
- Result after testing: LEGO SPIKE Prime remains the active platform.

### Decision: Use Three Ultrasonic Sensors

- Date: 2026-07-11
- Context: The new robot uses LEGO ultrasonic sensors on the left, middle/front, and right.
- Options considered: Camera/vision, ToF sensors, gyroscope, ultrasonic wall sensing.
- Decision: Use left/right ultrasonic sensors for wall distance and middle/front ultrasonic for safety/obstacle distance.
- Reasoning: This matches the new LEGO build and gives simple distance feedback for first autonomous driving tests.
- Tradeoffs: Ultrasonic sensors can reflect poorly from angled surfaces and may need filtering.
- Test evidence: 20 cm ultrasonic calibration recorded for left, middle/front, and right sensors.
- Result after testing: Sensors are usable for wall distance and front safety, with more distance/angle tests recommended.

### Decision: Use Pybricks MicroPython

- Date: 2026-07-11
- Context: The project moved away from Arduino C++.
- Options considered: SPIKE app blocks, LEGO Python, Pybricks MicroPython.
- Decision: Use Pybricks MicroPython.
- Reasoning: Pybricks gives clean text-based Python control of SPIKE Prime motors and sensors and makes tuning constants easy.
- Tradeoffs: Requires Pybricks firmware/workflow and careful documentation so judges can reproduce uploads.
- Test evidence: Active Pybricks program controls motors, reads ultrasonic sensors, and resets/reads hub heading.
- Result after testing: Pybricks remains the active programming platform.

### Decision: Use Rear-Wheel Drive With A Differential Gear System

- Date: 2026-07-11
- Context: The LEGO version uses a SPIKE Large Angular Motor for propulsion and a SPIKE Medium Angular Motor for steering.
- Options considered: Direct rear axle drive, rear-wheel drive with differential gearing, front-wheel drive, differential steering.
- Decision: Use rear-wheel drive through a differential gear system, with a separate front steering motor.
- Reasoning: The differential lets the rear wheels rotate at different speeds in turns, reducing tire scrub and making cornering smoother. The SPIKE Large Angular Motor drives a 20-tooth double bevel gear into the differential's 28-tooth gear, giving an approximate 20:28 reduction for more torque at the rear axle.
- Tradeoffs: The drivetrain is mechanically more complex and needs careful alignment so gears do not bind.
- Test evidence: Current robot completes 3 Open Challenge laps.
- Result after testing: Differential drivetrain retained because it drives smoothly and supports 3-lap Open Challenge runs.

### Decision: Use SPIKE Prime Integrated Gyro

- Date: 2026-07-11
- Context: The SPIKE Prime Hub includes an integrated gyro/IMU that Pybricks can read for heading feedback.
- Options considered: No gyro, external IMU, SPIKE Prime integrated gyro.
- Decision: Use the SPIKE Prime integrated gyro for heading and turn feedback.
- Reasoning: It is built into the hub, reduces wiring, and can be reset/read directly from Pybricks.
- Tradeoffs: Heading accuracy depends on hub orientation, flat placement, reset procedure, and drift testing.
- Test evidence: Hub orientation and heading reset procedure documented; internet reference for bad-case drift recorded.
- Result after testing: MadBoy-specific gyro drift measurement remains a future calibration task.

### Decision: Use OpenMV H7 For Vision

- Date: 2026-07-11
- Context: The Obstacle Challenge requires reliable red/green obstacle awareness.
- Options considered: Ultrasonic-only obstacle strategy, LEGO color sensor, OpenMV H7 camera.
- Decision: Use OpenMV H7 as the vision module.
- Reasoning: OpenMV H7 can run MicroPython vision code on the camera and is suitable for color/object detection experiments. It communicates with the SPIKE Prime Hub through the UART protocol on port C, while the PUPRemote/LPF2 Python libraries handle message packaging in code.
- Tradeoffs: Requires camera mounting, lighting calibration, and reliable UART message handling in the main robot logic.
- Test evidence: Obstacle detection is working and the red/green strategy is ready and working.
- Result after testing: Continue collecting formal run/score evidence.

### Decision: Do Not Use Parking

- Date: 2026-07-21
- Context: The team does not plan to park or start from the parking area.
- Options considered: Implement parking, start from parking area, or skip parking.
- Decision: Do not implement parking behavior for the current strategy.
- Reasoning: The current focus is Open Challenge consistency and working Obstacle Challenge detection/avoidance.
- Tradeoffs: Parking-specific points are not targeted by this strategy.
- Test evidence: Parking is intentionally not used.
- Result after testing: Not planned.

## Risks And Mitigations

| Risk | Impact | Mitigation | Status |
| --- | --- | --- | --- |
| Ultrasonic readings bounce on angled walls | Robot may steer incorrectly | Test at many distances and add filtering if needed | Basic 20 cm test complete; angled-wall testing remains future work |
| Steering motor center depends on last adjustment | Robot drifts left or right after centering | Add a repeatable center reset/calibration procedure before each run | Current test shows drift direction depends on last steering adjustment |
| Rear differential binds or slips | Robot loses speed or turns inconsistently | Check gear alignment and test both rear wheels under load | No binding/slipping observed; LEGO gears drive smoothly |
| Steering sign is reversed | Robot steers into walls | Low-speed sign test and `STEERING_SIGN` constant | Tested: `STEERING_SIGN = 1` steers away from left wall |
| Steering linkage binds at full lock | Front wheels may not reach commanded angle | Limit steering to about 45 degrees left/right and inspect the 12-tooth to 20-tooth gear linkage | Current code clamps to +/-45 degrees |
| Gyro heading drifts | Turns or lap logic become inaccurate | Reset heading at start and run drift tests | Reference value documented; MadBoy drift measurement remains future work |
| OpenMV lighting changes | Red/green classification becomes unreliable | Calibrate thresholds under field lighting | Detection/strategy working; formal lighting accuracy count remains future work |
| LEGO frame flexes during run | Sensor angle and steering geometry change | Reinforce chassis and inspect after each run | Pre-run structure check documented |
| Hub battery is low | Motor power changes | Charge before runs and record battery state | No noticeable slowdown reported; exact runtime not tracked |

## Iterations

| Version | Change | Why It Changed | Evidence |
| --- | --- | --- | --- |
| v0.1 | Arduino prototype with BMI160 and VL53L1X sensors | Initial control experiment | Git history |
| v0.2 | LEGO SPIKE Prime with 3 ultrasonic sensors and Pybricks | New team hardware direction | Current repository |
| v0.3 | Added integrated gyro and OpenMV H7 vision module | Better heading feedback and obstacle color detection | Current repository |

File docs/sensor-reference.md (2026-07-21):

# Sensor Reference Values

This file records internet-sourced reference values for sensors used on MadBoy. These values are not a replacement for team testing; they are starting points for calibration and test targets.

## LEGO SPIKE Prime Ultrasonic / Distance Sensor

| Item | Reference Value | Source |
| --- | --- | --- |
| Official product range | 1-200 cm | LEGO Education |
| Official product accuracy | +/- 1 cm | LEGO Education |
| Pybricks practical distance range | 40-2000 mm | Pybricks learning material |
| Pybricks invalid/no reading value | 2000 mm | Pybricks API docs |

Notes:

- Use +/- 10 mm as the first acceptance target for controlled distance tests.
- Test each of the three sensors separately because mounting angle, target material, and ultrasonic reflections can change results.
- Pybricks may report 2000 mm when no valid distance is measured, so robot logic should treat 2000 mm as far/open or invalid depending on the state.

## SPIKE Prime Integrated Gyro / IMU

No official universal drift rate for the SPIKE Prime integrated gyro was found. Pybricks documents behavior that matters for calibration:

| Item | Reference Behavior | Source |
| --- | --- | --- |
| Heading source | The hub estimates heading by integrating gyroscope rotation | Pybricks PrimeHub docs |
| Per-hub scale variation | A hub may report a repeatable value different from 360 degrees for one full turn; Pybricks gives 357 degrees for a 360-degree turn as an example | Pybricks PrimeHub docs |
| Correction method | `heading_correction` can scale future `hub.imu.heading()` values after measuring the hub's full-rotation result | Pybricks PrimeHub docs |
| Stationary recalibration | Pybricks can treat the hub as stationary after measurements stay below thresholds for one second | Pybricks PrimeHub docs |
| Default stationary angular threshold | 2 deg/s | Pybricks PrimeHub docs |
| Default stationary acceleration threshold | 2500 mm/s^2 | Pybricks PrimeHub docs |
| Internet-reported bad-case drift | Up to about 1 deg/s in a user report when the gyro was behaving incorrectly | FIRST LEGO League forum |

Competition test target:

- Record measured heading drift while the robot is still for 1 minute and 3 minutes.
- Record heading error after repeated 90-degree and 360-degree turns.
- If the hub consistently under-reports or over-reports a full turn, document the measured value and tune `heading_correction`.
- Use 1 deg/s only as a conservative internet-reported bad-case reference, not as MadBoy's measured drift.

## Sources

- LEGO Education Technic Distance Sensor: https://education.lego.com/en-us/products/lego-technic-distance-sensor/45604/
- Pybricks UltrasonicSensor API: https://docs.pybricks.com/en/latest/pupdevices/ultrasonicsensor.html
- Pybricks sensor learning material: https://pybricks.com/learn/sensors/responding-sensor-values/
- Pybricks PrimeHub IMU docs: https://docs.pybricks.com/en/latest/hubs/primehub.html
- Pybricks gyro calibration discussion: https://github.com/pybricks/support/issues/933
- FIRST LEGO League forum gyro drift report: https://forums.firstinspires.org/forum/general-discussions/first-programs/first-lego-league/the-challenge/programming-ab/94247-gyro-calibration-and-drift

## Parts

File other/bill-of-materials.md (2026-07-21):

# Bill Of Materials

List the parts used to build the LEGO SPIKE Prime robot.

Actual team spending for the current robot is 0 USD because the parts used for MadBoy were already available to the team. The estimated costs below are replacement costs for another team trying to reproduce the same electronics in July 2026.

## Main Components

| Part | Quantity | Purpose | Actual Team Cost | Estimated Replacement Cost | Notes |
| --- | ---: | --- | ---: | ---: | --- |
| LEGO SPIKE Prime Hub | 1 | Main controller and power source | 0 USD | about 280 USD | Runs Pybricks MicroPython; market estimate |
| SPIKE Large Angular Motor | 1 | Rear-wheel drive | 0 USD | about 80 USD | Drives the rear differential gear system |
| SPIKE Medium Angular Motor | 1 | Front steering | 0 USD | about 90 USD | Controls the steering linkage |
| LEGO ultrasonic/distance sensor | 3 | Left, middle/front, and right distance sensing | 0 USD | about 150 USD total | Estimated at about 50 USD each |
| OpenMV H7 camera | 1 | Vision and red/green obstacle detection | 0 USD | about 69 USD | Communicates with SPIKE Prime Hub through UART on port C |
| LEGO wheels/tires | 4 | Movement | 0 USD | Already available / variable | Wheel diameter about 5.5 cm |
| LEGO Technic differential/gears | 1 set | Rear differential drive system | 0 USD | Already available / variable | 20-tooth drive gear, 28-tooth differential gear, three 12-tooth bevel gears |
| LEGO Technic beams/frames/pins/gears | 1 build set | Chassis and mounts | 0 USD | Already available / variable | Documented in `../models/Robot_Design.io` |

Estimated replacement subtotal for main electronics: about 669 USD.

## Power Components

| Part | Quantity | Voltage/Current | Notes |
| --- | ---: | --- | --- |
| SPIKE Prime rechargeable battery | 1 | Hub battery | Included with the SPIKE Prime Hub / available to team |
| SPIKE Prime charger/cable | 1 | Charging/upload support | Already available |

## Optional Or Future Components

| Part | Quantity | Purpose | Notes |
| --- | ---: | --- | --- |
| OpenMV communication hardware | 1 | Connect OpenMV H7 to SPIKE Prime Hub | UART communication on port C; PUPRemote/LPF2 used as Python libraries |
| Extra LEGO motor | 0 | Backup or later mechanism | Not used |

## Cost Sources

- LEGO 45601 Large Hub market estimate: BrickPicker / BrickEconomy market listings.
- LEGO 45602 Large Angular Motor estimate: reseller listings.
- LEGO 45603 Medium Angular Motor estimate: BricksDirect / BrickEconomy market listings.
- LEGO 45604 Distance Sensor estimate: Brickipedia MSRP, Investabrick, and current reseller listings.
- OpenMV H7 estimate: DigiKey OpenMV Cam H7 listing.

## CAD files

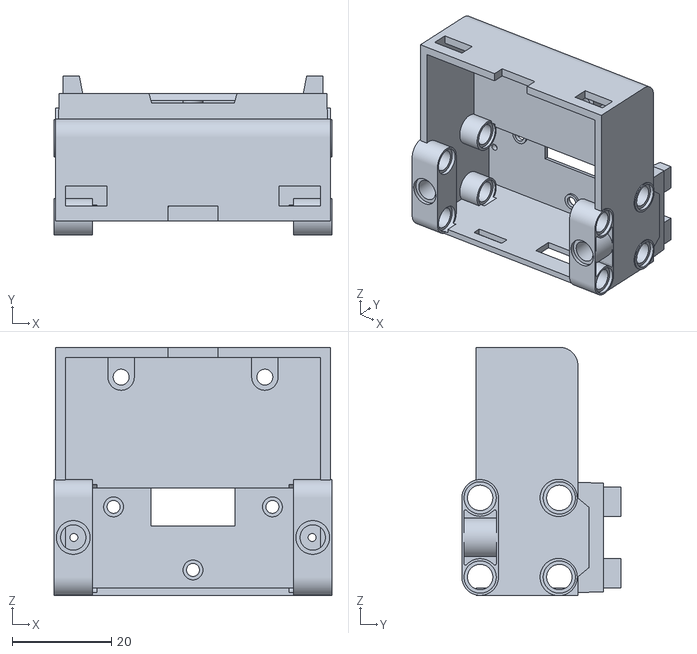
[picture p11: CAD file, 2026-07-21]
models/openmv-camera-case.stl
56.0 x 32.1 x 50.0

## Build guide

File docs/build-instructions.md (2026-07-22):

# Build Instructions

The complete LEGO construction guide for MadBoy is stored in `../models/Robot_Design.io`.

Open `../models/Robot_Design.io` with Studio 2.0 to view the full 3D model and follow the included step-by-step building instructions. This Studio file is the official mechanical construction reference for the robot, including the chassis, motor mounts, steering linkage, sensor positions, OpenMV mount, and rear differential drivetrain.

The remaining notes in this document summarize the measurements, wiring, and pre-run checks needed after building the robot from the Studio file.

## Mechanical Construction Source

| Item | Construction Evidence |
| --- | --- |
| Full LEGO model | `../models/Robot_Design.io` |
| Step-by-step build instructions | Included inside `../models/Robot_Design.io` |
| OpenMV H7 camera case | `../models/openmv-camera-case.stl` |
| Vehicle photos | `../v-photos/` |

Keep `../models/Robot_Design.io` synchronized with the physical robot whenever the build changes.

## Electronics And Ports

The current robot uses the LEGO SPIKE Prime Hub, Powered Up motors, three ultrasonic sensors, the hub's integrated gyro/IMU, and an OpenMV H7 camera. The hub battery powers LEGO devices connected to the hub. Before each run, charge the hub battery to full, check all cables, make sure the LEGO structure is steady and sturdy, and confirm that every part is in place.

Keep the port map updated in `../schemes/port-map.md`.

Confirmed port map:

| Port | Device |
| --- | --- |
| A | SPIKE Large Angular Motor for rear-wheel drive |
| B | Left ultrasonic sensor |
| C | OpenMV H7 via UART |
| D | Middle/front ultrasonic sensor |
| E | SPIKE Medium Angular Motor for front steering |
| F | Right ultrasonic sensor |
| Hub IMU | Integrated gyro/heading |

## Chassis Dimensions

| Measurement | Approximate Value | How It Was Measured |
| --- | ---: | --- |
| Length | 20 cm | Front-most point to rear-most point |
| Width | 13.5 cm | Left-most point to right-most point |
| Height | 22 cm | Floor to highest point |
| Wheelbase | 10.3 cm | Front axle center to rear axle center |
| Front track width | 11.2 cm | Center of left front wheel to center of right front wheel |
| Rear track width | 11.2 cm | Center of left rear wheel to center of right rear wheel |
| Wheel diameter | 5.5 cm | Outside tire diameter |

MadBoy fits within the WRO Future Engineers 2026 maximum robot size of 30 cm length x 20 cm width x 30 cm height.

## Rear Differential Drivetrain

The rear drive motor is a LEGO SPIKE Prime Large Angular Motor. It drives a beige 20-tooth double bevel gear, which drives the 28-tooth gear on the LEGO differential. The external gear ratio is approximately 20:28, so the differential output turns at about 0.71x motor-gear speed and gains about 1.4x torque before drivetrain losses.

The LEGO differential must contain three 12-tooth bevel gears inside it. Those internal bevel gears allow the left and right rear wheels to rotate at different speeds during turns.

## Front Steering Linkage

The front steering is powered by a LEGO SPIKE Prime Medium Angular Motor. The motor drives a 12-tooth gear, which drives a 20-tooth gear connected to an arm. This arm moves the steering system and turns the front wheels.

The maximum steering range is about 45 degrees left and 45 degrees right. The Pybricks program clamps steering commands to the same range.

## Sensor And Camera Placement

| Component | Placement |
| --- | --- |
| Left ultrasonic sensor | About 5 cm from the floor, facing outward to the left |
| Middle/front ultrasonic sensor | About 6 cm from the floor, facing forward |
| Right ultrasonic sensor | About 5 cm from the floor, facing outward to the right |
| OpenMV H7 camera | Lens about 17.5 cm from the floor, tilted about 5 degrees |
| SPIKE Prime Hub | Lying flat, with USB port facing the robot's left side |

The OpenMV H7 communicates with the SPIKE Prime Hub on port C using the UART protocol. The PUPRemote/LPF2 Python libraries are used in the OpenMV and Pybricks code to package the messages.

## Software Upload

1. Install Pybricks firmware on the SPIKE Prime Hub if it is not already installed.
2. Open `https://code.pybricks.com/`.
3. Connect the SPIKE Prime Hub.
4. Open the program for the current stage: `../src/pybricks/open_round.py` for Open Round, or `../src/pybricks/obstacle_course.py` when the Obstacle Course code is published.
5. Confirm the port constants match `../schemes/port-map.md`.
6. Upload or run the program from Pybricks Code.
7. Start with the robot lifted so wheels can spin safely.
8. Verify steering center and steering direction.
9. Verify the gyro heading resets to 0 at the start line.
10. Place the robot on the field and test at low `DRIVE_POWER`.

## Pre-Run Checklist

- [x] Hub battery charged to full.
- [x] All cables are connected firmly.
- [x] LEGO structure is rigid, steady, and sturdy.
- [x] Motors, sensors, camera, and gears are in place.
- [x] Wheels and gears move freely.
- [x] Rear differential gear system rotates smoothly and contains three 12-tooth bevel gears.
- [x] Steering reaches about 45 degrees left/right without binding; center reset still needs consistency tuning.
- [x] Drive motor direction is correct.
- [x] Left ultrasonic sensor reports fresh readings.
- [x] Middle/front ultrasonic sensor reports fresh readings.
- [x] Right ultrasonic sensor reports fresh readings.
- [x] Integrated gyro heading reset procedure is documented.
- [x] OpenMV H7 is mounted securely.
- [x] OpenMV H7 communication method is documented.
- [x] Front safety stop threshold tested.
- [x] `STEERING_SIGN` tested at low speed.
- [x] Emergency stop or safe shutdown procedure is known by the team.

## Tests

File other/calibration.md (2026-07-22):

# Calibration Notes

Record the calibration procedure used before runs.

Reference sensor values from LEGO and Pybricks are summarized in `../docs/sensor-reference.md`.

## Pre-Run Power And Structure Check

- Charge the SPIKE Prime Hub battery to full.
- Check that all cables are connected firmly.
- Make sure the robot is steady and sturdy.
- Confirm that motors, ultrasonic sensors, OpenMV H7 camera, wheels, and gears are in place.
- Battery runtime note: the hub battery lasts a long time in team testing, but exact runtime has not been tracked yet.

## Steering Center

- Put the wheels straight before starting the program.
- The current Pybricks program resets the steering motor angle at startup.
- If the robot drifts, adjust the mechanical center first, then tune software constants.

| Date | Robot Version | Steering Center Method | Result | Notes |
| --- | --- | --- | --- | --- |
| 2026-07-21 | MadBoy | Center steering before straight run | Drifts left or right depending on the last steering adjustment | Needs repeatable centering reset/calibration before each run |

## Steering Direction

- Run at low speed.
- Place the robot closer to the left wall than the right wall.
- Confirm it steers away from the left wall.
- If it steers toward the wall, change `STEERING_SIGN` in the stage program being tested.

| Date | STEERING_SIGN | Result | Notes |
| --- | ---: | --- | --- |
| 2026-07-21 | 1 | Pass: closer to left wall makes robot steer right/away | Keep current sign unless linkage/code direction changes |

## Ultrasonic Sensors

- Verify that left, middle/front, and right sensors report fresh readings.
- Test readings at known distances such as 100 mm, 200 mm, 300 mm, and 500 mm.
- Test angled walls because ultrasonic reflections can change with angle.
- First target: stay within +/- 10 mm under controlled conditions, based on the LEGO Education +/- 1 cm distance sensor reference.

| Sensor | Actual Distance | Measured Distance | Error | Notes |
| --- | ---: | ---: | ---: | --- |
| Left | 20.0 cm | 20.5 cm | +0.5 cm | Within +/- 1 cm reference target |
| Middle/front | 20.0 cm | 21.2 cm | +1.2 cm | Slightly outside +/- 1 cm target; retest at more distances |
| Right | 20.0 cm | 20.1 cm | +0.1 cm | Within +/- 1 cm reference target |

## SPIKE Prime Integrated Gyro

- Place the robot flat on the field.
- The SPIKE Prime Hub is mounted lying flat, with the USB port facing the robot's left side.
- Align the robot to the known starting direction.
- Press the start button so the Pybricks program calls `hub.imu.reset_heading(0)`.
- Record heading drift while the robot is still and after driving.
- No official universal drift rate was found. Pybricks documents per-hub heading variation, and an internet user report describes bad-case SPIKE Prime yaw drift up to about 1 deg/s when the gyro behaves incorrectly. Measure this specific hub and document any `heading_correction` value.

| Date | Robot Version | Test | Result | Notes |
| --- | --- | --- | --- | --- |
| 2026-07-21 | MadBoy | Heading reset | Procedure documented | Hub lies flat with USB port facing left |
| Internet reference | SPIKE Prime Hub | Bad-case drift report | Up to about 1 deg/s | Not measured on MadBoy |
| Future measurement | MadBoy | Still drift test | Not measured yet | Measure before competition |
| Future measurement | MadBoy | Driving drift test | Not measured yet | Measure before competition |

## OpenMV H7 Vision

- Mount the camera at the documented height and angle.
- Calibrate red and green obstacle detection under field lighting.
- Record false positives and false negatives.
- Send OpenMV H7 data to the SPIKE Prime Hub using UART communication on port C; PUPRemote/LPF2 are the Python libraries used to package the messages.

| Date | Lighting | Target | Threshold/Model | Result | Notes |
| --- | --- | --- | --- | --- | --- |
| 2026-07-21 | Team test lighting | Red obstacle | OpenMV color strategy | Detection/strategy working | Formal accuracy count still needed |
| 2026-07-21 | Team test lighting | Green obstacle | OpenMV color strategy | Detection/strategy working | Formal accuracy count still needed |

## Control Tuning

Record values and behavior after each tuning change.

| Date | DRIVE_POWER | SIDE_BALANCE_GAIN | FRONT_STOP_MM | FRONT_RESUME_MM | Test Result | Notes |
| --- | ---: | ---: | ---: | ---: | --- | --- |
| 2026-07-21 | 35 | 0.18 | 180 mm | 260 mm | Sometimes centered; sometimes closer to one wall than the other | Tune side gain after steering center reset is more repeatable |

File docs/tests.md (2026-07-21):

# Testing Workflow

Use this file to prove that the LEGO SPIKE Prime robot was tested and improved over time.

Internet-sourced reference values are summarized in `sensor-reference.md`. Team measurements should be recorded below and compared against those references.

## Test Log

| Date | Robot Version | Test | Result | Change Made |
| --- | --- | --- | --- | --- |
| 2026-07-21 | MadBoy | Open Challenge 3-lap run | Completes 3 laps | Continue tuning consistency |
| 2026-07-21 | MadBoy | Ultrasonic 20 cm accuracy check | Left 20.5 cm, front 21.2 cm, right 20.1 cm | Retest front sensor and collect more distances |
| 2026-07-21 | MadBoy | Front safety stop | Object at 10 cm; robot stopped at about 10 cm +/- 1 cm | Keep front stop threshold conservative |
| 2026-07-21 | MadBoy | Steering center straight-run check | Robot drifts left or right depending on the last steering adjustment | Improve repeatable steering center reset/calibration |
| 2026-07-21 | MadBoy | Steering sign test | When closer to the left wall, robot steers right/away from the wall | Keep `STEERING_SIGN = 1` |
| 2026-07-21 | MadBoy | Wall-centering observation | Sometimes centered; sometimes closer to one wall than the other | Tune `SIDE_BALANCE_GAIN` and improve steering center reset |
| 2026-07-21 | MadBoy | Rear differential smoothness | Drives smoothly using LEGO parts and gears; no binding/slipping observed | Keep checking gear alignment before runs |
| 2026-07-21 | MadBoy | Hub battery qualitative runtime check | Battery lasts a long time in testing; no noticeable slowdown reported | Exact runtime not tracked yet |
| 2026-07-21 | MadBoy | Obstacle detection and strategy status | Detection is working; red/green strategy is ready and working | Add formal run/score evidence later |
| 2026-07-21 | MadBoy | Parking strategy decision | Parking and start-from-parking are not used | No parking behavior planned |

## Recommended Tests

- Ultrasonic sensor accuracy test.
- Integrated gyro heading reset and drift test.
- OpenMV H7 red/green detection test.
- Front safety stop test.
- Steering center test.
- Steering sign test.
- Rear differential smoothness test.
- Straight-line wall-centering test.
- Corner behavior test.
- Open Challenge lap consistency test.
- Obstacle detection and avoidance test.
- Hub battery runtime test.
- Full three-minute run test.

## Metrics To Record

- Completed laps.
- Time per lap.
- Number of wall touches.
- Number of obstacle touches.
- Stop distance from obstacle.
- Average left/right distance error.
- Steering correction range.
- Differential gear smoothness and wheel slip.
- Gyro heading drift over time.
- OpenMV red/green classification accuracy.
- Hub battery state before and after run.
- Any manual interventions.

## Ultrasonic Accuracy

Reference target: LEGO lists the Technic Distance Sensor at 1-200 cm with +/- 1 cm accuracy. Pybricks learning material uses 40-2000 mm as the practical ultrasonic range, and the Pybricks API can return 2000 mm when no valid distance is measured.

| Date | Sensor | Actual Distance | Measured Distance | Error | Notes |
| --- | --- | ---: | ---: | ---: | --- |
| 2026-07-21 | Left | 20.0 cm | 20.5 cm | +0.5 cm | Within +/- 1 cm reference target |
| 2026-07-21 | Front | 20.0 cm | 21.2 cm | +1.2 cm | Slightly outside +/- 1 cm target; retest |
| 2026-07-21 | Right | 20.0 cm | 20.1 cm | +0.1 cm | Within +/- 1 cm reference target |

## Gyro / IMU Tests

Reference note: no official universal SPIKE Prime gyro drift rate was found. Pybricks documents per-hub full-turn scale variation and supports `heading_correction`, so drift/heading error should be measured on this hub. As an internet-reported bad-case reference, a FIRST LEGO League forum post reported SPIKE Prime yaw drift as high as about 1 deg/s when the gyro was behaving incorrectly.

| Date | Robot Version | Test | Result | Notes |
| --- | --- | --- | --- | --- |
| 2026-07-21 | MadBoy | Heading reset at start line | Procedure documented | MadBoy-specific drift not measured yet |
| Internet reference | SPIKE Prime Hub | Bad-case drift report | Up to about 1 deg/s | Not measured on MadBoy; use only as conservative reference |
| Future measurement | MadBoy | Drift after 1 minute | Not measured yet | Measure this robot before competition |
| Future measurement | MadBoy | Drift after 3 minutes | Not measured yet | Measure this robot before competition |

## OpenMV H7 Vision Tests

| Date | Lighting | Target | Distance | Result | Notes |
| --- | --- | --- | ---: | --- | --- |
| 2026-07-21 | Team test lighting | Red obstacle | Not measured | Detection/strategy working | Add formal accuracy count later |
| 2026-07-21 | Team test lighting | Green obstacle | Not measured | Detection/strategy working | Add formal accuracy count later |

## Control Tuning Notes

| Date | Drive Power | Side Gain | Front Stop | Front Resume | Track Result | Notes |
| --- | ---: | ---: | ---: | ---: | --- | --- |
| 2026-07-21 | 35 | 0.18 | 180 mm | 260 mm | Sometimes centered; sometimes closer to one wall | Tune after steering center reset improves |

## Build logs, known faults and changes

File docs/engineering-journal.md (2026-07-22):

# Engineering Journal

Use this document to tell the story of the robot's engineering process, not only the final design. The current robot direction is LEGO SPIKE Prime with Pybricks MicroPython, three ultrasonic sensors, the integrated SPIKE Prime gyro/IMU, and an OpenMV H7 camera.

## Team

- Team name: Mechanicous
- Country/region: Palestine
- Members: Ibrahim Daraghma, Ali Foqha
- Season: WRO Future Engineers 2026

## 1. Mobility And Mechanical Design

Describe the LEGO chassis, steering, drive system, stability, and mechanical constraints.

Include:

- Why LEGO SPIKE Prime / Technic construction was chosen.
- Rear-wheel drive mechanism using the SPIKE Large Angular Motor.
- Rear differential gear system, gear ratio, wheel diameter, and expected speed.
- Front steering mechanism using the SPIKE Medium Angular Motor, steering limits, and turn radius.
- Wheelbase, track width, sensor positions, and important dimensions.
- Stability, weight distribution, and structural rigidity.
- Mechanical tests and changes between versions.
- Diagrams or links to files in `../models/` and `../v-photos/`.

## 2. Power And Sensor Architecture

Describe how the SPIKE Prime Hub powers the system, how the ultrasonic sensors are placed, how the integrated gyro is used, and how the OpenMV H7 camera is mounted.

Include:

- SPIKE Prime Hub battery and charging procedure.
- Motor and sensor port map.
- Left, middle/front, and right ultrasonic sensor placement.
- SPIKE Prime Hub orientation for integrated gyro heading.
- OpenMV H7 camera position, purpose, and communication method.
- Why ultrasonic sensors were chosen for this version.
- Calibration procedure, gyro reset procedure, vision calibration, and sensor accuracy tests.
- Failure modes such as ultrasonic reflections, loose cables, low battery, or bad sensor angles.
- Diagrams or links to files in `../schemes/`.

## 3. Software Architecture And Obstacle Strategy

Describe the Pybricks software and the robot behavior.

Include:

- Stage programs in `../src/pybricks/open_round.py` and `../src/pybricks/obstacle_course.py`.
- State machine or flowchart.
- Wall-centering strategy using left/right ultrasonic sensors.
- Heading feedback from the SPIKE Prime integrated gyro.
- Front safety and obstacle approach logic using the middle/front ultrasonic sensor.
- Open Challenge lap strategy.
- Obstacle Challenge red/green obstacle strategy using OpenMV H7; current status is working.
- Parking is intentionally not used because the team will not park or start from the parking area.
- Edge cases and how the robot recovers.
- Links to `software-architecture.md`.

## 4. Systems Thinking And Engineering Decisions

Explain design tradeoffs and how subsystems interact.

Include:

- Why the team moved from the Arduino prototype to LEGO SPIKE Prime.
- Why Pybricks MicroPython was selected.
- Why three ultrasonic sensors were selected.
- Why the integrated SPIKE Prime gyro is used for heading feedback.
- Why OpenMV H7 is used for vision/color detection and UART communication with PUPRemote/LPF2 libraries.
- Constraints: size, weight, time, processing, power, reliability, budget, available LEGO parts.
- Major decisions and alternatives considered.
- Iterations from the old prototype to the current LEGO version.
- Risks and mitigations.
- What changed after testing.
- Links to `decisions.md`.

## 5. Reproducibility And GitHub Quality

Explain how someone else can rebuild the robot from this repository.

Include:

- LEGO build instructions, photos, or digital model files.
- Bill of materials.
- SPIKE Prime port map.
- Ultrasonic sensor placement diagram.
- SPIKE Prime Hub orientation and gyro reset notes.
- OpenMV H7 mounting and communication notes.
- Pybricks upload steps.
- Test procedure and tuning values.
- Version or release notes.
- Commit history with meaningful changes.

## Submission Checklist

- [ ] README completed.
- [ ] Engineering journal completed.
- [ ] Pybricks code uploaded in `../src/`.
- [ ] LEGO build files/photos uploaded in `../models/`.
- [ ] Port map and sensor diagrams uploaded in `../schemes/`.
- [ ] Gyro and OpenMV H7 documentation uploaded in `../schemes/`.
- [ ] Vehicle photos uploaded in `../v-photos/`.
- [ ] Team photos uploaded in `../t-photos/`.
- [ ] Demo video link added in `../video/video.md`.
- [ ] Tests documented in `tests.md`.
- [ ] Decisions documented in `decisions.md`.
- [ ] Meaningful commits are visible on GitHub.

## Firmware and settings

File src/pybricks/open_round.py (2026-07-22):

"""
Open Round template for MadBoy.

Goal:
    Drive three Open Challenge laps using the SPIKE Prime integrated gyro for
    heading stability and the left/right/front ultrasonic sensors for distance
    correction and safety.

This file is a publishable template. Tune constants on the real field before
using it as the final competition program.
"""

from pybricks.hubs import PrimeHub
from pybricks.parameters import Button, Color, Direction, Port, Stop
from pybricks.pupdevices import Motor, UltrasonicSensor
from pybricks.tools import StopWatch, wait


# ---------------------------------------------------------------------------
# Ports
# ---------------------------------------------------------------------------

DRIVE_MOTOR_PORT = Port.A
LEFT_SENSOR_PORT = Port.B
FRONT_SENSOR_PORT = Port.D
STEERING_MOTOR_PORT = Port.E
RIGHT_SENSOR_PORT = Port.F


# ---------------------------------------------------------------------------
# Tunable Settings
# ---------------------------------------------------------------------------

DRIVE_MOTOR_DIRECTION = Direction.CLOCKWISE
STEERING_MOTOR_DIRECTION = Direction.CLOCKWISE

DRIVE_POWER = 35

STEERING_CENTER_DEG = 0
STEERING_LEFT_LIMIT_DEG = -45
STEERING_RIGHT_LIMIT_DEG = 45
STEERING_SPEED_DPS = 500
STEERING_SIGN = 1

FRONT_STOP_MM = 180
FRONT_RESUME_MM = 260
MAX_VALID_DISTANCE_MM = 2000

SIDE_TARGET_MM = 210
SIDE_BALANCE_GAIN = 0.16
GYRO_HEADING_GAIN = 0.55

LOOP_PERIOD_MS = 40
OPEN_ROUND_TARGET_LAPS = 3
OPEN_ROUND_TIMEOUT_MS = 180000

# Update this with lap counting from your final field logic when available.
ESTIMATED_LAP_TIME_MS = 55000


# ---------------------------------------------------------------------------
# Hardware
# ---------------------------------------------------------------------------

hub = PrimeHub()
drive_motor = Motor(DRIVE_MOTOR_PORT, positive_direction=DRIVE_MOTOR_DIRECTION)
steering_motor = Motor(
    STEERING_MOTOR_PORT,
    positive_direction=STEERING_MOTOR_DIRECTION,
)

left_sensor = UltrasonicSensor(LEFT_SENSOR_PORT)
front_sensor = UltrasonicSensor(FRONT_SENSOR_PORT)
right_sensor = UltrasonicSensor(RIGHT_SENSOR_PORT)


# ---------------------------------------------------------------------------
# Helpers
# ---------------------------------------------------------------------------

def clamp(value, lower, upper):
    return max(lower, min(upper, value))


def read_distance(sensor):
    """Return a filtered ultrasonic reading in millimeters."""
    try:
        distance = sensor.distance()
    except OSError:
        return None

    if distance is None or distance <= 0:
        return None

    return min(distance, MAX_VALID_DISTANCE_MM)


def wait_for_start():
    hub.light.on(Color.ORANGE)
    print("Open Round ready. Press center button.")

    while Button.CENTER not in hub.buttons.pressed():
        wait(20)

    while Button.CENTER in hub.buttons.pressed():
        wait(20)


def reset_heading():
    hub.imu.reset_heading(0)


def read_heading():
    return hub.imu.heading()


def center_steering():
    steering_motor.reset_angle(STEERING_CENTER_DEG)
    steering_motor.run_target(
        STEERING_SPEED_DPS,
        STEERING_CENTER_DEG,
        then=Stop.HOLD,
        wait=True,
    )


def set_steering(target_degrees):
    target_degrees = clamp(
        target_degrees,
        STEERING_LEFT_LIMIT_DEG,
        STEERING_RIGHT_LIMIT_DEG,
    )
    steering_motor.run_target(
        STEERING_SPEED_DPS,
        target_degrees,
        then=Stop.HOLD,
        wait=False,
    )


def stop_robot():
    drive_motor.stop()
    set_steering(STEERING_CENTER_DEG)


def calculate_distance_correction(left_mm, right_mm):
    """Use side sensors to keep the robot balanced between the walls."""
    if left_mm is None and right_mm is None:
        return 0

    if left_mm is None:
        side_error = SIDE_TARGET_MM - right_mm
    elif right_mm is None:
        side_error = left_mm - SIDE_TARGET_MM
    else:
        side_error = left_mm - right_mm

    return STEERING_SIGN * SIDE_BALANCE_GAIN * side_error


def calculate_gyro_correction(current_heading, target_heading):
    """Steer back toward the target heading measured at the start line."""
    heading_error = current_heading - target_heading
    return -STEERING_SIGN * GYRO_HEADING_GAIN * heading_error


def calculate_open_round_steering(left_mm, right_mm, current_heading, target_heading):
    distance_correction = calculate_distance_correction(left_mm, right_mm)
    gyro_correction = calculate_gyro_correction(current_heading, target_heading)
    return STEERING_CENTER_DEG + distance_correction + gyro_correction


def front_is_blocked(front_mm, was_blocked):
    if front_mm is None:
        return True

    if was_blocked:
        return front_mm <= FRONT_RESUME_MM

    return front_mm < FRONT_STOP_MM


def estimated_laps_completed(timer_ms):
    return timer_ms // ESTIMATED_LAP_TIME_MS


def run_open_round():
    timer = StopWatch()
    target_heading = read_heading()
    front_blocked = False

    while timer.time() < OPEN_ROUND_TIMEOUT_MS:
        left_mm = read_distance(left_sensor)
        front_mm = read_distance(front_sensor)
        right_mm = read_distance(right_sensor)
        heading_deg = read_heading()
        lap_count = estimated_laps_completed(timer.time())

        if lap_count >= OPEN_ROUND_TARGET_LAPS:
            break

        front_blocked = front_is_blocked(front_mm, front_blocked)

        if front_blocked:
            hub.light.on(Color.RED)
            stop_robot()
        else:
            hub.light.on(Color.GREEN)
            steering_target = calculate_open_round_steering(
                left_mm,
                right_mm,
                heading_deg,
                target_heading,
            )
            set_steering(steering_target)
            drive_motor.dc(DRIVE_POWER)

        print(
            "mode:open",
            "lap:",
            lap_count,
            "left:",
            left_mm,
            "front:",
            front_mm,
            "right:",
            right_mm,
            "heading:",
            heading_deg,
            "blocked:",
            front_blocked,
        )
        wait(LOOP_PERIOD_MS)

    stop_robot()
    hub.light.on(Color.BLUE)
    print("Open Round complete.")


# ---------------------------------------------------------------------------
# Main
# ---------------------------------------------------------------------------

center_steering()
wait_for_start()
reset_heading()

try:
    run_open_round()
finally:
    stop_robot()

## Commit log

2026-07-11 Switch documentation and code to LEGO SPIKE Prime Pybricks
2026-07-11 Document SPIKE motors and rear differential
2026-07-11 Document integrated gyro and OpenMV H7 plan
2026-07-11 Add sourced sensor accuracy references
2026-07-18 Update current robot behavior
2026-07-21 Add OpenMV camera case model
    [openmv-camera-case.stl]
2026-07-21 Document robot chassis dimensions
2026-07-21 Document sensor and camera placement
2026-07-21 Document SPIKE hub gyro orientation
2026-07-21 Document rear differential drivetrain
2026-07-21 Document front steering linkage
2026-07-21 Document pre-run power checklist
2026-07-21 Clarify OpenMV UART communication wording
2026-07-21 Add ultrasonic calibration results
2026-07-21 Add gyro drift reference value
2026-07-21 Add steering center test result
2026-07-21 Add steering sign test result
2026-07-21 Add battery runtime observation
2026-07-21 Add BOM replacement cost estimates
2026-07-22 Use stage-specific Pybricks programs
